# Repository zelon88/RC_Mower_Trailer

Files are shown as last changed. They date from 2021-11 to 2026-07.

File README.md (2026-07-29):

# RC_Mower_Trailer

## WORK IN PROGRESS!!!

A set of SCAD models to 3D Print & Manufacture your own tow-behind lawn mower for R/C trucks.

## Requirements

- Design is about 65% complete. All parts are still subject to change.
- 3D printer with 150mm × 150mm minimum build volume
- Tamiya High-Lift or compatible R/C truck (tow vehicle)
- 540 brushed motors × 2 (standard Silver Can or equivalent)
- 1/10th scale R/C servo × 2 (standard size)
- 1.9" or 2.2" R/C wheels × 4
- Standard R/C battery & ESC (×2, one per motor)
- Steel flat bar — 3.175mm (1/8") thickness for chassis rails & blades
- Standard M2.5, M3, & M5 hardware (screws, nuts, washers, lock washers)
- 10× thrust ball bearings & 2× flanged ball bearings (differential assembly)
- R4 series ball bearings — 1/4" ID × 1/2" OD × 3/16" width (blade carriers)
- Basic hand tools: drill press, files, soldering iron, screwdrivers

## Features At-A-Glance

* A hybrid assembly consisting of 3D printed & manufactured parts.
* Complete with detailed manufacturing & assembly instructions.
* Dual counter-rotating motors for exceptional torque & smoothness.
* Dual counter-rotating cutting blades for smooth, balanced operation.
* Differential gearbox provides rotational shock damping properties while ensuring both motors send power to both blades.
* Uses standard 540 brushed R/C motors, 1/10th scale R/C servos, standard R/C batteries, & 1.9" or 2.2" R/C wheels.
* Highly modular design with many interchangeable parts makes repairs simple & inexpensive.
* Industrial-grade engineering inspired by early 20th century tractors & farm equipment.
* Designed to be manufactured at home using residential-grade tooling & techniques.
* Designed to actually do work. Not a shelf queen. A functional piece of equipment.
* Designed with numerous safety features. See below for more safety information.
* Self-leveling suspension with adjustable ride height.
* Integrated hoppers collect grass clippings and dump them out at the push of a button.

## Features In-Depth

### Counter Rotating Blade Drivetrain

The cutting blades are powered in opposite directions by a pair of "Silver Can" brushed 540 DC electric motors typically found in entry-level R/C vehicles. This motor is inexpensive, reliable, and offers decent performance. The gearbox accepts standard size, standard rotation motors, so most R/C motors will fit.

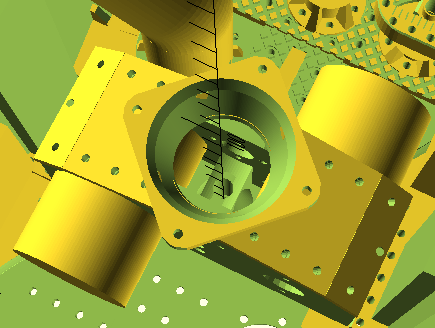
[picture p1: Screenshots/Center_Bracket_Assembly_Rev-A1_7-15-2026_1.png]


The rotation of the motors is joined via a Center Differential. This linked-rotation configuration allows for the equalization of impacts or over-torque events between both blades & both motors. The rotation of the blades being linked together means one blade acts as a flywheel & inertial damper for the other. It also means faster blade speed recovery after an impact, as each blade has torque from both motors. Finally, when our system impacts heavy debris; not all energy is lost like in separate blade systems. In our system, the impact energy is transferred to the opposite blade, actually increasing its velocity. This temporary over-speed condition acts as an inertial "capacitor" that stores energy to be distributed back to the slower blade via the center differential.

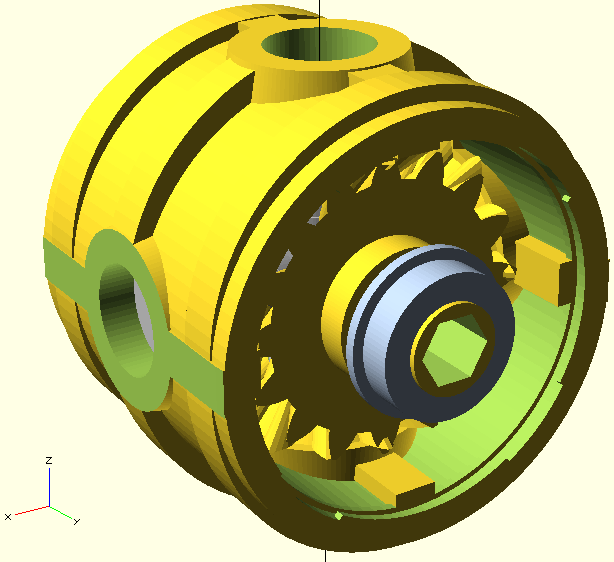
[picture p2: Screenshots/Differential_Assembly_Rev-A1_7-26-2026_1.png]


The differential itself is a modular 3D printable planetary unit measuring 21mm x 21mm x 21mm. Its assembly consists of 2 output gears, 4 planet gears, & a core block. The assembly is supported by 10× thrust ball bearings & 2× flanged ball bearings. Great care has been taken during design to ensure the differential assembly is isolated from shock, over-torque conditions, or unsupported side-loads.

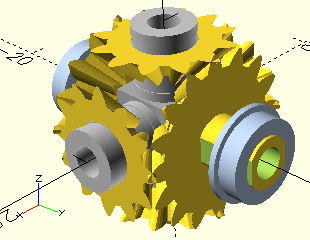
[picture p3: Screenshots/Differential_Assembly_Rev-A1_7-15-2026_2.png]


To compare; in systems with fully separate blade drive systems the energy contained within any blade is only equal to that of the mass of one blade. In our system; each blade contains the full potential energy of both rotating blades. When our system impacts heavy debris our blades keep more of their velocity and stability.

### Inertia Dampened Drivetrain

The drivetrain features dual Inertia Dampers located on either side of the center differential. The inertia dampers are designed to absorb, store, and redistribute kinetic energy from large impacts back into the drivetrain evenly over time. The compact dampers are integrated inside the pulley system which drives the blades. Each damper features quad centering springs which provide 15 degrees of deflection in both clockwise & counter-clockwise directions for 30 degrees of total deflection.

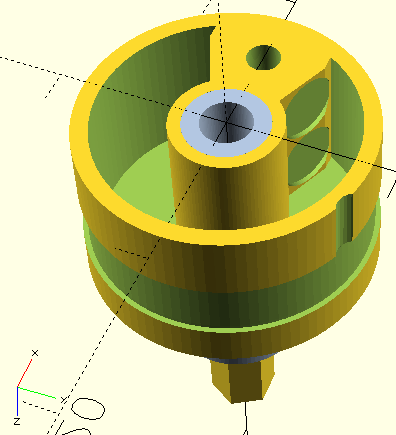
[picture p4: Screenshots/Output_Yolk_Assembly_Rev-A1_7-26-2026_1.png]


Each damper is designed in two main parts; a yolk & a cover. Both the cover & the yolk are open-ended interlocking drums. The drums can rotate independantly clockwise or counter-clockwise from one another via 3x internal ball bearings and a massive 18mm x 3.6mm tapered roller bearing integrated into the body of the two drums. Although the drums can rotate up to 15 degrees off-center from one another, they are pre-loaded to stay centered via 4x internal springs. The internal springs act to keep the drums centered, but will allow separation up to 15 degrees clockwise or counter-clockwise to absorb sudden drastic changes in load.

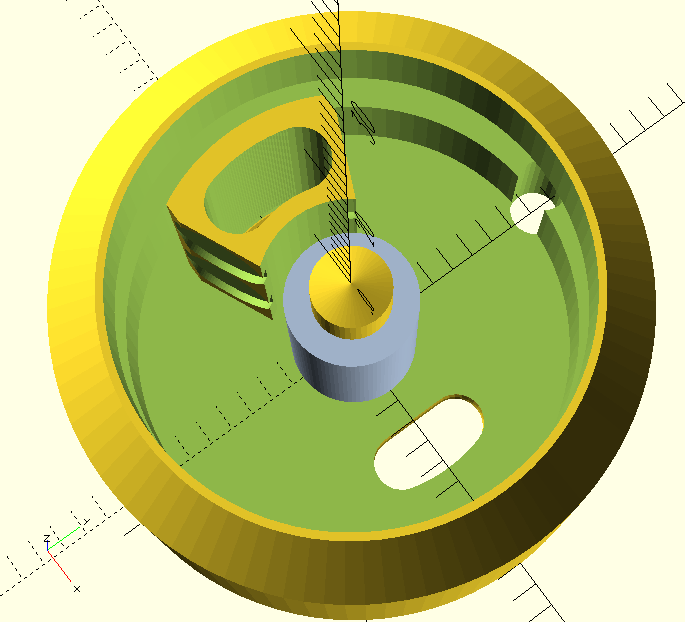
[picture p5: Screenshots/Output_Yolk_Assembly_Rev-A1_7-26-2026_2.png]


It is important to note that the motors are not protected by the inertial damper. The dampers exist to protect the differential gears from exposure to overwhelming force by spreading that force over a longer duration of time. The motors rotate the cover of the inertial damper, and the center differential is attached to the center yolk. When a blade decelerates due to impacted debris; the motor is also slowed instantly. Because the motor is located outside the protection of the damper, it's acceleration torque actually helps the inertial damper recover sooner. Additionally, the energy stored by the spring in the damper is redirected back into the motor as additional torque during re-acceleration. 

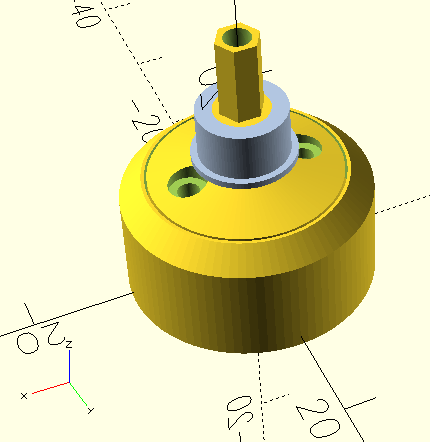
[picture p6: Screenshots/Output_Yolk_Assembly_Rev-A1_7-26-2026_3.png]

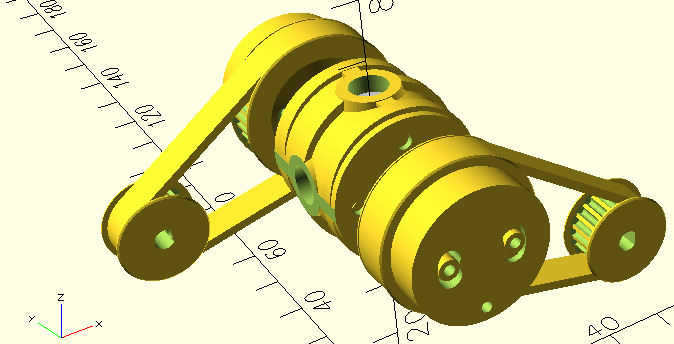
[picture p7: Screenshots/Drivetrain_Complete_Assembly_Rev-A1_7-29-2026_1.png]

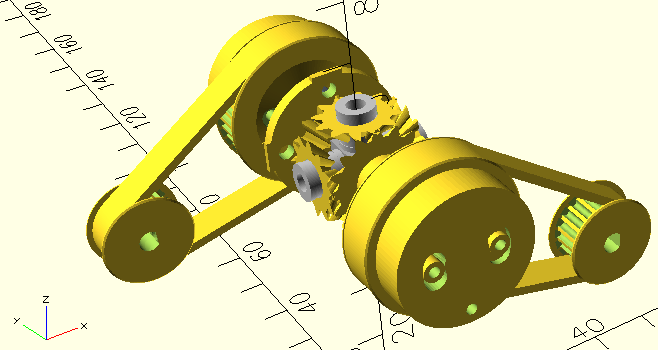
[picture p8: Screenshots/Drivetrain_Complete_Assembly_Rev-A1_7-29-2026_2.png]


Everything about our blade drive system is designed to control, absorb, store, & distribute kinetic energy in the most stable & efficient way possible.

### Steel Reinforced Chassis

Every design element has been carefully selected with heavy consideration towards containing debris, managing vibration, surviving impact, & providing durability.

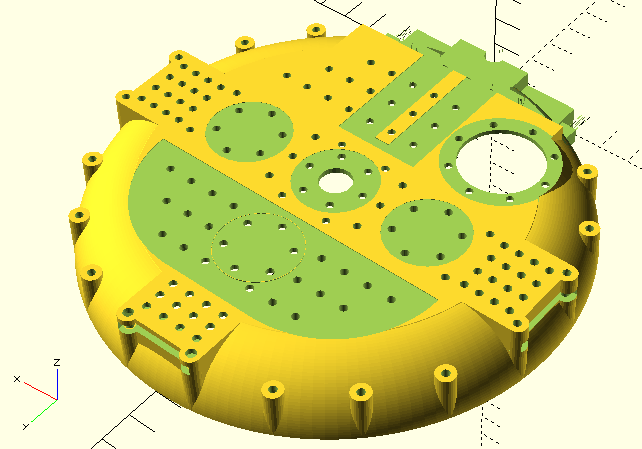
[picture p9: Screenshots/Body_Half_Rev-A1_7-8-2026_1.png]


The mower chassis is comprised of a steel frame with a thickness between 3.175mm and 6.35mm. Wrapped around this steel frame is an impact resistant plastic body with a thickness between 4mm and 14mm. The average material thickness around the rotating blades is 10mm with additional plastic gussets and steel screws built into the body every 19 degrees around the circumference of the blade.

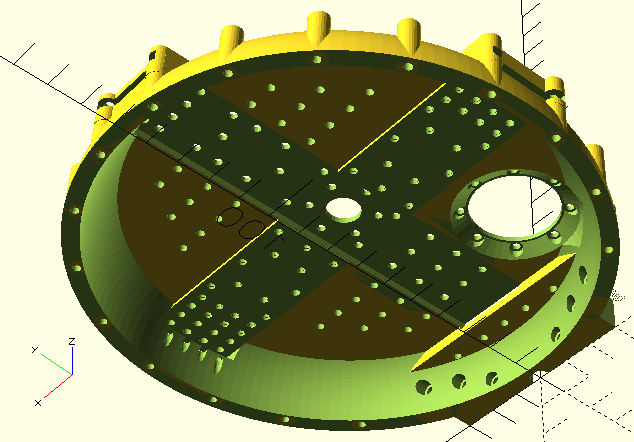
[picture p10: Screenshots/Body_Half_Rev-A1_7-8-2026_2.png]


### Captured Blade Carrier Design

The cutting blades are made from 3.175mm thick steel flat bar. The blades rotate in opposite directions to minimize vibration and prevent build-up of gyroscopic forces that could destabilize the mower. The blades are installed via a very long grade 8 bolt which traverses a through hole in the center of the blade. This bolt is then installed into the chassis from the bottom-up through three stages of ball bearings.

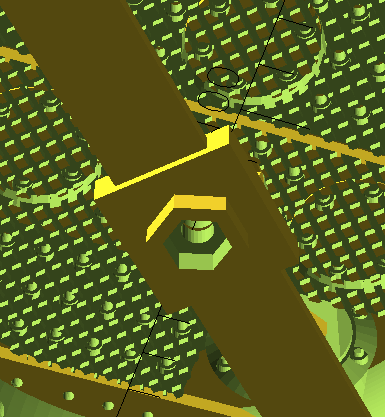
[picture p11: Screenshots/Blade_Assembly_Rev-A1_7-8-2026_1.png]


Due to the length of the bolt being greater than the clearance from the blade to the ground; it is impossible for a spinning blade to "fall out" or "swing out" from underneath a running mower.

### Redundant Rollover Protection

The mower features blueprints & instructions for building dual Rollover Protection Switches which disable the mower automatically in the event that it tips over. The adjustable switches will prevent the blade motors and blades from spinning while the mower is inverted. The switches self-reset once the mower has been placed upright again.

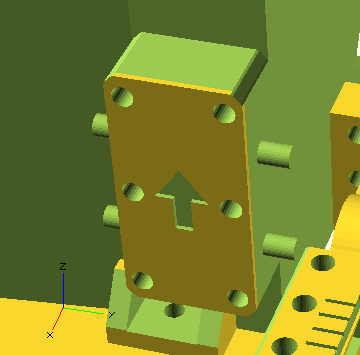
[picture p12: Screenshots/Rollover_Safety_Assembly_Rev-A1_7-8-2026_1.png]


The switches are incredibly small, at only 30mm × 15mm × 8.5mm each. They feature a modular design with optional input/output terminals on left & right sides.

When using only one input & one output terminal, observed current is similar to a 14 AWG wire. When using both sets of terminals, observed current is similar to a 12 AWG wire. Two switches are included in this mower design, wired in series to provide double fault tolerant rollover protection.

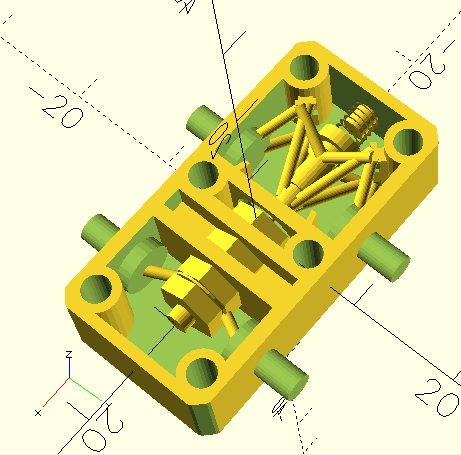
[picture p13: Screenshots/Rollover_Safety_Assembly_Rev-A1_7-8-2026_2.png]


### Multi-Mode Self-Leveling Suspension

The mower features independent self-leveling suspension on all 4 wheels & side attachments. The suspension features prominent adjustment screws that enable the operator to quickly & easily adjust cutting height & side attachment height. The geometry of the suspension is designed to be identical between front, rear, and side suspension arms to simplify assembly & field repair.

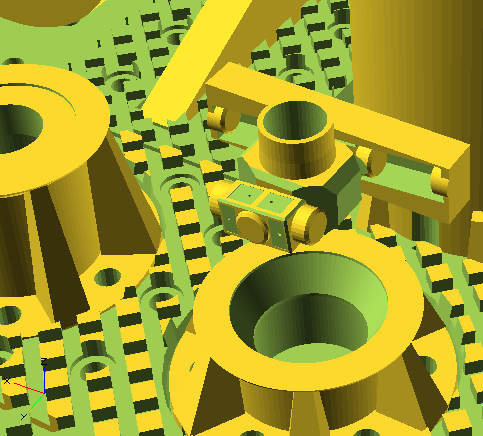
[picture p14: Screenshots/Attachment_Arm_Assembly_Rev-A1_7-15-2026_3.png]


The geometry for the suspension is contained in modular "Ramp Inserts" which feature a reversible design. When these inserts are installed into the suspension arms in the "reversed" position, the damping behaviour of the suspension is altered significantly.

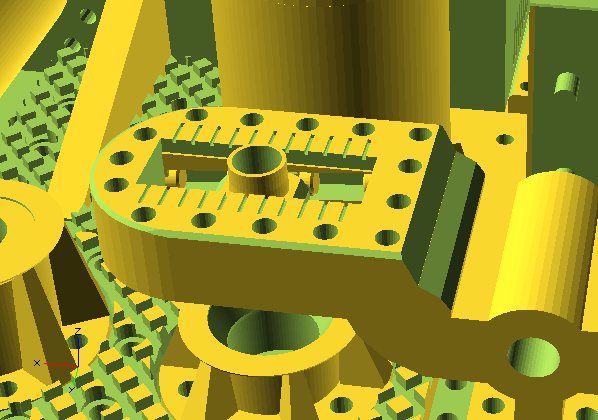
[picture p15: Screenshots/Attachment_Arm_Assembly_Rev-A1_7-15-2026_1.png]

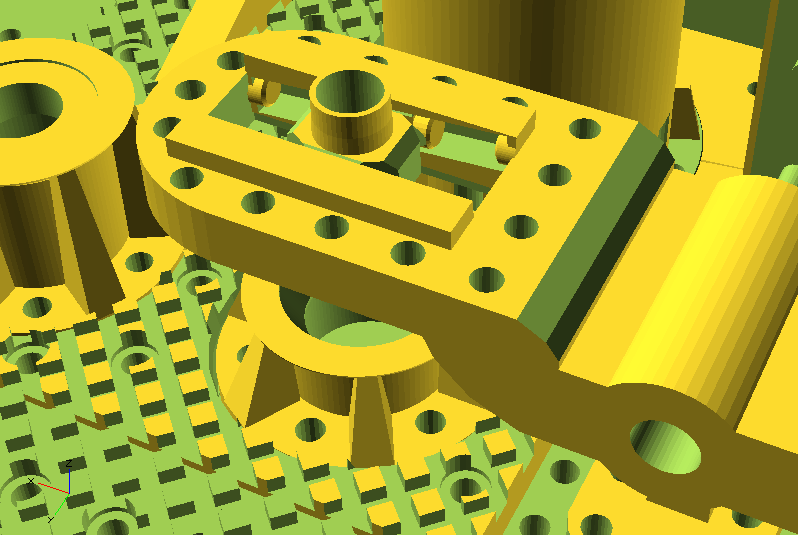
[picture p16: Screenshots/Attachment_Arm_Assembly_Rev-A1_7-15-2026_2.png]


In the "**Default**" ramp insert position, the mower will "**Follow The Ground**." In this configuration the wheel will primarily travel and absorb bumps in the downward direction only. The adjustment screws that set height will set the "absolute floor" for ride-height that the suspension will not allow height to go beneath. When one wheel falls into a rut, that wheel will be allowed to gently follow the rut, and recover to its original position naturally. The default configuration allows each suspension arm to independently absorb low spots in terrain without the entire body "tilting" or the blades "digging" into the ground. The mower will seem to be "latched" to the ground. This configuration is best suited for relatively smooth lawns.

In the "**Reversed**" ramp insert position, the mower will "**Stay Level**." In this configuration the wheel will travel and absorb bumps in both the upward and downward directions. The adjustment screws that set height will set the "absolute ceiling" for ride-height that the suspension will not allow height to go above. Due to the spring rate being very low, the result is the suspension will sag somewhere in the middle of its ride height. This will allow the wheel to travel and absorb bumps in both the upward & downward directions. The adjustment screw effectively sets a middle resting position for the suspension. The reversed configuration allows each suspension arm to independently absorb high spots and low spots in extremely uneven terrain, but with greater risk for the body "tilting" or the blades "digging" into the ground. The mower will seem to be "floating" over the ground. This configuration is best suited for tall grass, uneven terrain, or heavy brush.

The same suspension logic applies to the side attachment suspension assembly. The parts and geometry are all identical, but the "Reversed" position is used as the default ramp insert configuration.

Damping is achieved via friction dampers integrated into the Attachment Adjustment Arm Crossheads. The crossheads bear the load of the suspension from the suspension arm to the adjustment screw. They feature grease pockets, grease galleries, calculated surface area & carefully crafted geometry to optimize load handling & damping characteristics in an especially reliable & cost effective way.

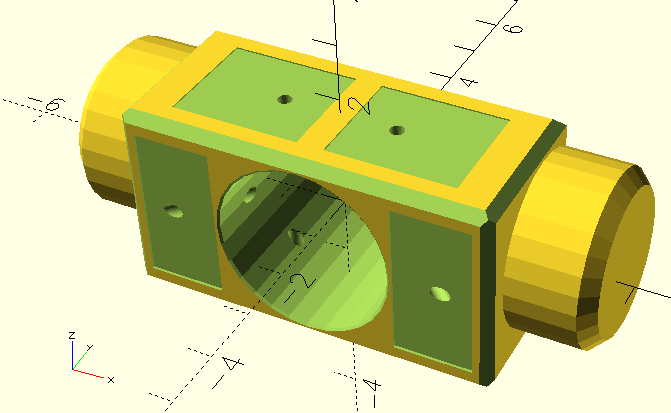
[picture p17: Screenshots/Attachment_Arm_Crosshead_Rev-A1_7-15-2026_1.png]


## More Screenshots

### [View All Screenshots](https://github.com/zelon88/RC_Mower_Trailer/tree/main/Screenshots)

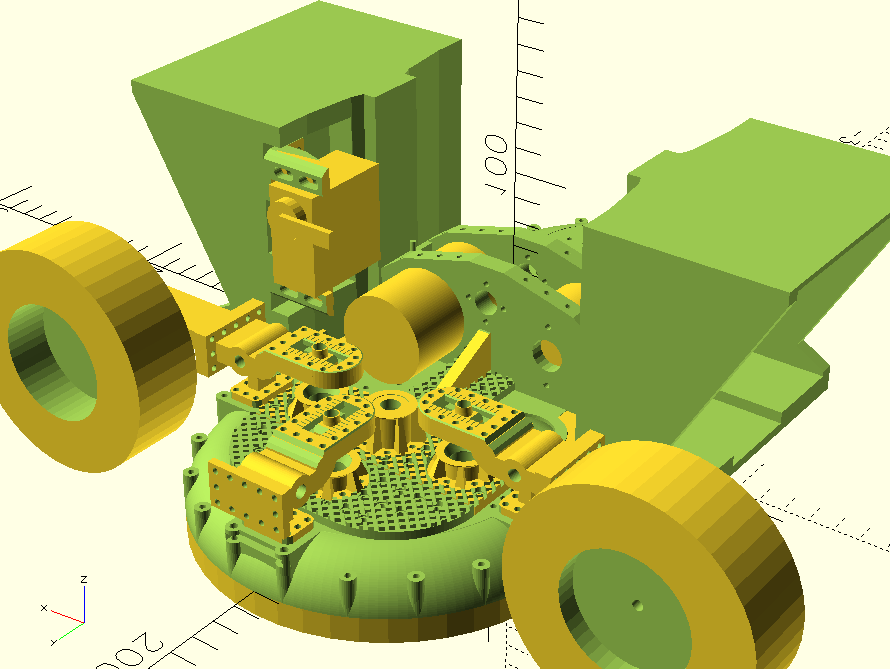
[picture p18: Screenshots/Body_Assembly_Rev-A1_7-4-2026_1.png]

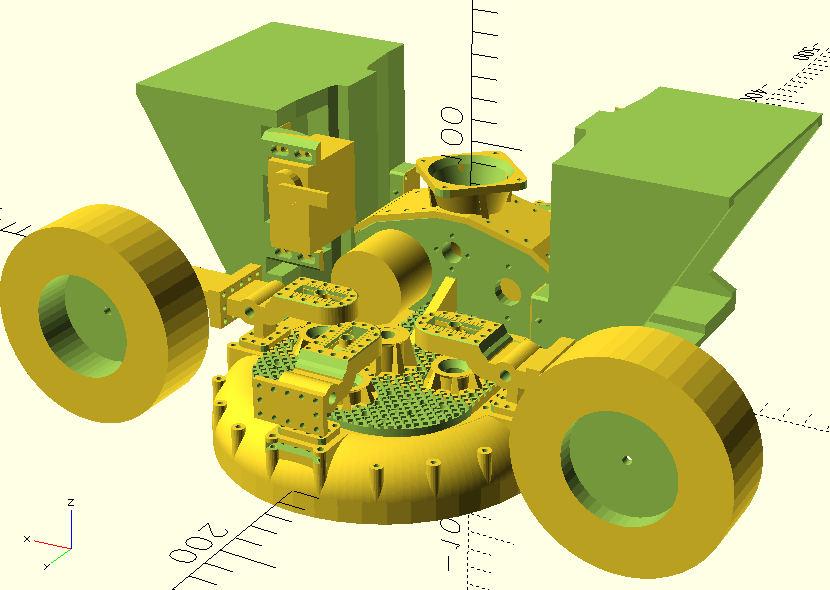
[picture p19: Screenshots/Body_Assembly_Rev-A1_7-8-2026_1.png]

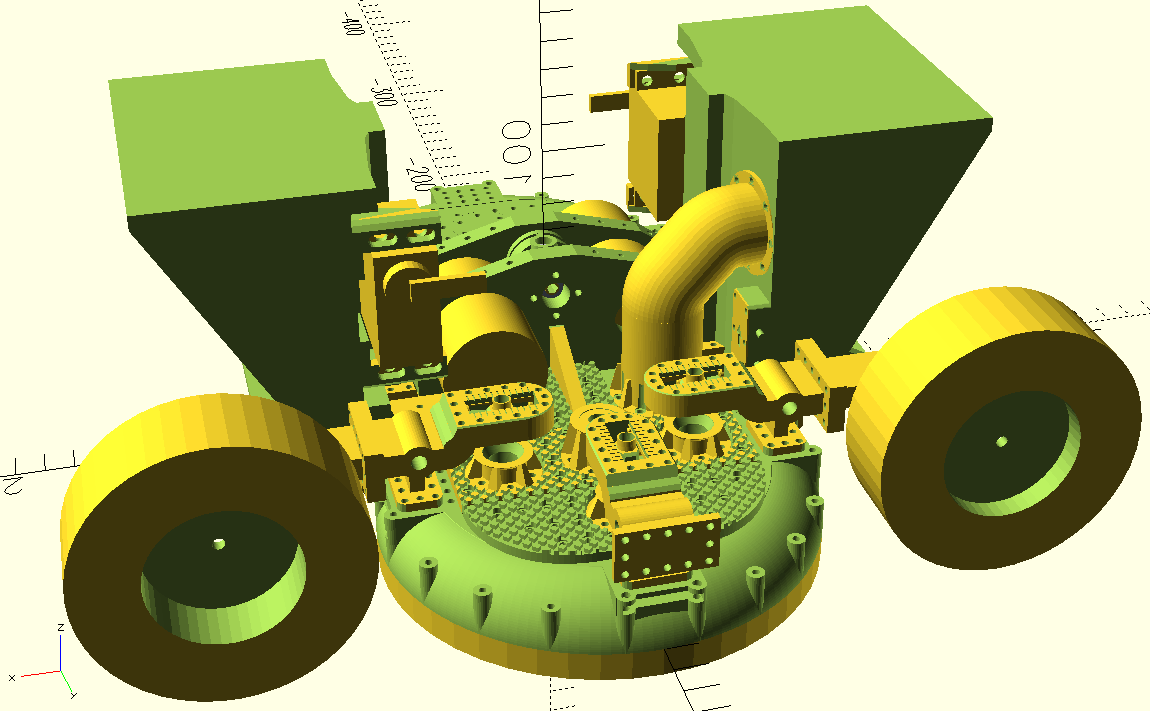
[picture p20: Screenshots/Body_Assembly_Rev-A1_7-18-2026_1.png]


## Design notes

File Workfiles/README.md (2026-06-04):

# RC_Mower_Trailer
 A set of SCAD models for a tow-behind lawn mower attachment for R/C trucks.

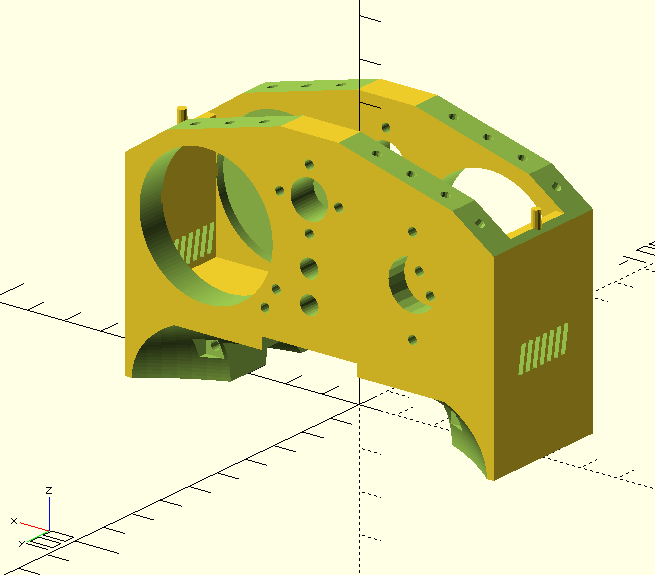
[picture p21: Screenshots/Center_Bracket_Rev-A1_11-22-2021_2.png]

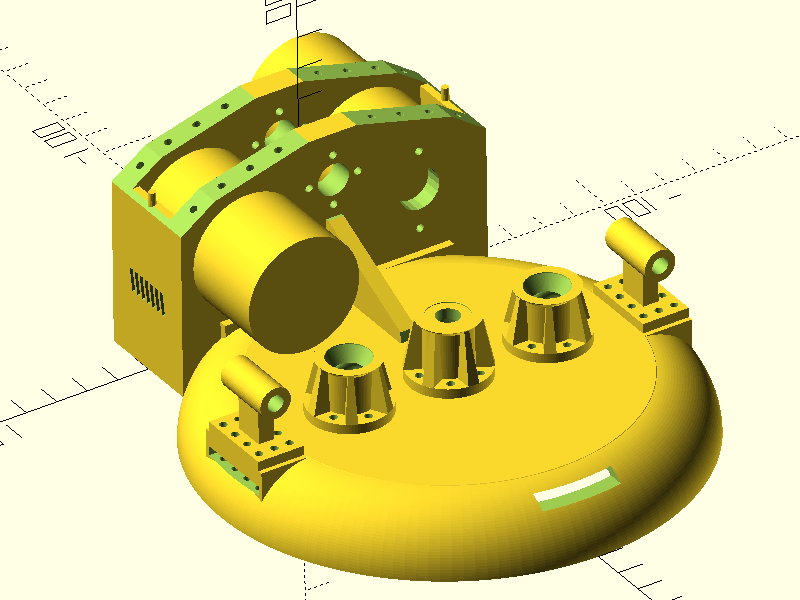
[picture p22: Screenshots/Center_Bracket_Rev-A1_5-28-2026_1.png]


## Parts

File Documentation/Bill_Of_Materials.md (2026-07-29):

# R/C Mower Trailer — Bill of Materials

**Status: design phase.** Counts here are taken from the SCAD sources, not from a build.
Anything marked ⚠ has not been verified against a physical assembly and anything marked
❓ could not be counted from the files available. This gets rebuilt properly during the
manufacturing engineering pass, when print orientation and hardware lengths are settled.

Quantities are **per mower** unless stated otherwise.

---

## 1. Drivetrain

Fully counted from source. This is the part of the machine that is dimensionally closed —
every item below is driven by a specific feature in a specific file.

### 1.1 Center Differential — printed

| Qty | Part | File |
|---|---|---|
| 1 | Differential Housing | `Differential_Housing.scad` |
| 1 | Differential Housing Cap | `Differential_Housing_Cap.scad` |
| 1 | Core Block | `Differential_Gears.scad` → `cross_block_core()` |
| 2 | Output Gear (16T bevel, with shaft) | `Differential_Gears.scad` → `side_gear_with_shaft()` |
| 4 | Planet Gear (12T bevel) | `Differential_Gears.scad` → `planet_bevel_gear()` |

### 1.2 Center Differential — hardware

| Qty | Item | Notes |
|---|---|---|
| 10 | F3-6-2.8M thrust bearing | 8 on the planets (2 each), 2 inboard on the output gears |
| 2 | 5×8×2.5mm **flanged** ball bearing | One per output shaft, flange toward the gear |
| 2 | M2.5 wave compression washer | One per output shaft |
| 4 | M2.5 conical compression washer | One per planet, small dia toward the gear |
| 4 | M2.5 planet gear screw | Threads into the core block; use thread locker |
| 1 | M2.5 output gear through bolt ⚠ | Length not yet fixed — spans both output gears |
| — | M2.5 flat washers | **Shimmed at assembly.** Equal count each side of each planet, added until gear slack is gone. Buy generously. |
| 4 | M2.5 screw, housing to cap | Holes at X=±8 and Z=45/61 in both parts |

### 1.3 Inertia Dampers — printed (**×2 dampers**)

| Qty (each) | Qty (total) | Part | File |
|---|---|---|---|
| 1 | 2 | Output Yolk | `Differential_Output_Yolk.scad` |
| 1 | 2 | Output Yolk Cover | `Differential_Output_Yolk_Cover.scad` |
| 30 | **60** | Conical Roller Bearing | `Differential_Output_Yolk_Roller_Bearing.scad` |

The roller count is set by `roller_qty` in the yolk's assembly block. 30 gives 0.232mm of
gap between rollers on the 9.16685mm pitch radius. Print spares — they are 1.7mm across
and will be lost.

### 1.4 Inertia Dampers — hardware (**×2 dampers**)

| Qty (each) | Qty (total) | Item | Notes |
|---|---|---|---|
| 3 | 6 | 3×5×2.5mm ball bearing | Stacked at Z=0, 2.5, 5 on the yolk pin |
| 1 | 2 | 5×8×2.5mm **flanged** ball bearing | At Z=14.5 |
| 1 | 2 | 5×8×2.5mm ball bearing | At Z=14.5 |
| 2 | 4 | M1.6 screw ⚠ | Through the standoff bosses at X=±5.25. Length not yet fixed — the boss is 9.5625mm and the head recesses into the yolk. |
| 2 | 4 | M1.6 lock nut | Lands on the boss end, not on the cover cap |
| 4 | 8 | Compression spring ⚠ | "Clicky pen" springs, 2 per trapezoid face. Free length and rate not yet specified. |

### 1.5 Belt Drive

| Qty | Item | Notes |
|---|---|---|
| 2 | Motor Pulley, 19T | Printed — `Differential_Motor_Pulley.scad` |
| 2 | M2.5 set screw ⚠ | Forms its own thread in the tapered hole. ~4mm long; not yet fixed. |
| 2 | GT2 belt, **120mm** (60T), 6mm wide, closed loop | Fibreglass corded |
| — | Driven pulley, 38T | **Not a separate part** — cut into the Output Yolk Cover |

Ratio is exactly 2.000:1. Centre distance is fixed by the Center Bracket at 30.8707mm;
a 120mm belt wants 30.9083mm, so it runs 0.0376mm slack with no adjuster anywhere. Do not
substitute a 122mm belt — that wants 31.4786mm and will be visibly loose.

### 1.6 Motors

| Qty | Item | Notes |
|---|---|---|
| 2 | 540 brushed motor, "Silver Can" or equivalent | 3.175mm armature shaft **with a flat**. The pulley bore is a D and relies on it. |
| 2 | Brushed ESC ⚠ | Rating not yet specified |

---

## 2. Chassis and Body — partial

Counted where files were available. **Fastener counts here are not yet trustworthy**: many
holes are shared between mating parts, so a hole is not a screw, and several referenced
`Workfiles/` hole-pattern modules were not available to expand.

| Qty | Part | File | Confidence |
|---|---|---|---|
| 2 | Body Half | `Body_Half.scad` | counted |
| 1 | Center Bracket | `Center_Bracket.scad` | counted |
| 2 | Center Bracket Support | `Center_Bracket_Support.scad` | counted |
| 1 | Clippings Exhaust Header | `Clippings_Exhaust_Header.scad` | counted |
| ❓ | Body Skirt | `Body_Skirt.scad` | not available |
| ❓ | Body Stiffener, Inner / Outer / Center | `Body_Stiffener_*.scad` | not available |
| ❓ | Center Bracket Skid Plate | referenced in Body Half Assembly | not available |
| ❓ | Hopper Base, Hopper Bracket | referenced in Body Half Assembly | not available |
| ❓ | Attachment Hinge Boss | referenced in Body Half Assembly | not available |

### Steel stock

| Item | Notes |
|---|---|
| Flat bar, 3.175mm (1/8") | Chassis rails, X and Y slots in the torus base. Slot is 25.6mm wide × 3.175mm. |
| Flat bar, 3.175mm (1/8") | Cutting blades ❓ — length and count not counted |

---

## 3. Not yet counted

These need their files before anything honest can be said about them:

- **Blade carriers** — README calls for R4 bearings (1/4" ID × 1/2" OD × 3/16"), quantity unknown
- **Blade retention bolts** — grade 8, "longer than ground clearance"; length not fixed
- **Suspension** — Attachment Adjustment Arms, ramp inserts, crossheads, springs, adjustment screws
- **Rollover Safety Switches** — 2 off, plus their gravity pins, castle nuts and terminals
- **Wheels** — 4× 1.9" or 2.2" R/C
- **Servos** — 2× standard 1/10 scale
- **Batteries** — 2× standard R/C
- **Hoppers** and their dump mechanism
- **General fasteners** — M2.5 / M3 / M5 screws, nuts, washers, lock washers across the whole machine

---

## 4. Open questions for the manufacturing pass

1. **Screw lengths are unspecified throughout.** Every ⚠ above is a length that needs
   measuring off an assembled stack rather than guessing from the model.
2. **The damper spring rate is undefined.** Preload sets the ±15° deflection behaviour,
   and the spring is currently described only as "clicky pen spring".
3. **Roller count is a design choice, not a constraint.** 30 was chosen for spacing; more
   would spread the preload further, up to about 36 before they touch.
4. **The GT2 tooth profile is unverified.** It is the one set of numbers in the drivetrain
   taken from an external source rather than derived. Fit a real belt to a printed pulley
   before committing to a print run.
5. **Damper bearings are absent from the README requirements list.** It currently
   attributes 10 thrust and 2 flanged bearings to the differential only, which is correct
   as far as it goes, but the 6 + 2 + 2 in section 1.4 are additional and unlisted.

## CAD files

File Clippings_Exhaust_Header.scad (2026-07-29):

// ----------------------------------------------------------------------------------------------------
// PROJECT INFORMATION

// NAME:  R/C Mower Trailer
// REVISION:  A1
// START DATE:  8/20/2021
// CURRENT VERSION DATE:  9/8/2021
// LICENSE:  GPLv3
// AUTHOR:  Justin Grimes (@zelon88)
// DESCRIPTION:  A tow-behind lawn mowing attachment for retrofit onto low-speed R/C vehicles.
// ----------------------------------------------------------------------------------------------------

// ----------------------------------------------------------------------------------------------------
// PART INFORMATION

// NAME:  Clippings Exhaust Header
// REVISION:  A1
// START DATE:  7/4/2026
// CURRENT VERSION DATE:  7/16/2026
// AUTHOR:  Justin Grimes (@zelon88) & Copilot - Claude Sonnet 4.6.
// DESCRIPTION:
//    A clippings evacuation header routing grass clippings from the cutting deck to the hopper.
//    Features a bottom flange mating to Body_Half, an 8x rib reinforced straight tube, a first
//    45deg elbow, an extension pipe with an oval intermediate support ring (10x screw holes for
//    body attachment), a second 45deg elbow bringing the pipe to horizontal, a short horizontal
//    pipe section, and a terminal circular flange mating flush with the X face of the hopper.
//    The terminal flange faces world +X. index_angle introduces a small rotation that can be
//    zeroed to achieve exact X-perpendicular alignment if needed.
// FILE NAME: Clippings_Exhaust_Header.scad
// ----------------------------------------------------------------------------------------------------

// ----------------------------------------------------------------------------------------------------
// PRINTER CONFIGURATION
// [Printing instructions to be added]
// ----------------------------------------------------------------------------------------------------

// ----------------------------------------------------------------------------------------------------
// MANUFACTURING INSTRUCTIONS

// 1. Deburr all edges to break sharp edges.
// 2. Align bottom flange screw holes with Clippings_Flange_Screw_Holes() on Body_Half.
// 3. Fasten bottom flange with M2.5 screws.
// 4. Fasten oval intermediate ring to nearby body structure for pipe support.
// 5. Align terminal circular flange with matching hole in hopper X face and bolt together.
// ----------------------------------------------------------------------------------------------------

// ----------------------------------------------------------------------------------------------------
// MODULES

include <Workfiles/Clippings_Flange_Screw_Holes.scad>
// A module for cutting the 8x screw holes in the terminal X-facing circular flange.
include <Workfiles/Clippings_X_Flange_Screw_Holes.scad>
// ----------------------------------------------------------------------------------------------------

// ----------------------------------------------------------------------------------------------------
// GEOMETRY

module Clippings_Flange_Exhaust_Header() {
  // Primary dimensions.
  flange_r    = 18;   // Bottom flange outer radius.
  flange_t    = 2.5;  // Bottom flange thickness.
  flange_id   = 13;   // Bottom flange inner bore radius.
  tube_id     = 13;   // Tube inner radius (all sections).
  tube_od     = 14;   // Tube outer radius — 1mm wall (all sections).
  tube_h      = 35;   // Straight tube height above bottom flange.
  bend_r      = 14;   // Centerline bend radius — same for all elbows.
  bend_angle  = 45;   // First and second elbow bend angle from vertical (degrees).
  index_angle = 6.5;  // Z rotation orienting the first elbow toward the hopper.
                      // Set to 0 for exact world +X terminal flange alignment.
  ext_h       = 15;   // Extension pipe length between first and second elbows.
  pipe_x_h    = 7;    // Short pipe length in world +X direction after second elbow.

  // Rib dimensions.
  rib_base_d = flange_r - tube_od;
  rib_top_d  = 1.5;
  rib_base_w = 2.5;
  rib_top_w  = 1.2;
  rib_h      = 10;

  // Oval intermediate ring dimensions.
  oval_margin = 3;
  oval_t      = 2.5;
  oval_a_out  = tube_od / cos(bend_angle) + oval_margin;
  oval_b_out  = tube_od + oval_margin;
  oval_a_in   = tube_id / cos(bend_angle);
  oval_b_in   = tube_id;

  // Terminal circular flange dimensions (mates with hopper X face).
  x_flange_r  = 18;    // Terminal flange outer radius.
  x_flange_t  = 3;   // Flange plate thickness.

  difference() {
    union() {
      // Bottom flange plate.
      cylinder($fn=256, r=flange_r, h=flange_t, center=false);
      // Straight tube.
      translate([0, 0, flange_t]) cylinder($fn=256, r=tube_od, h=tube_h, center=false);
      // Tapered ribs (8x, between screw holes).
      for (i = [0:7]) {
        rotate([0, 0, i * 45 + 22.5])
        hull() {
          translate([tube_od + rib_base_d/2, 0, flange_t])
            cube([rib_base_d, rib_base_w, 0.01], center=true);
          translate([tube_od + rib_top_d/2, 0, flange_t + rib_h])
            cube([rib_top_d, rib_top_w, 0.01], center=true); } }
      // First 45deg elbow (vertical to 45deg tilt).
      rotate([0, 0, index_angle])
      translate([0, 0, flange_t + tube_h])
      translate([bend_r, 0, 0])
      rotate([0, 0, 180])
      rotate([90, 0, 0])
      rotate_extrude(angle=bend_angle, $fn=256)
        translate([bend_r, 0]) circle(r=tube_od, $fn=128);
      // Extension pipe.
      rotate([0, 0, index_angle])
      translate([0, 0, flange_t + tube_h])
      translate([bend_r*(1-cos(bend_angle)), 0, bend_r*sin(bend_angle)])
      rotate([0, 45, 0])
        cylinder($fn=128, r=tube_od, h=ext_h + 1, center=false);
      // Second 45deg elbow (pipe direction to horizontal = world +X approximately).
      rotate([0, 0, index_angle])
      translate([0, 0, flange_t + tube_h])
      translate([bend_r*(1-cos(bend_angle)), 0, bend_r*sin(bend_angle)])
      rotate([0, 45, 0])
      translate([0, 0, ext_h])
      translate([bend_r, 0, 0])
      rotate([0, 0, 180])
      rotate([90, 0, 0])
      rotate_extrude(angle=bend_angle, $fn=256)
        translate([bend_r, 0]) circle(r=tube_od, $fn=128);
      // Short pipe in world +X direction.
      // In pipe local frame, rotate([0,45,0]) aligns the cylinder axis with
      // local (sin45,0,cos45) = world +X. Terminal face is perpendicular to world +X.
      rotate([0, 0, index_angle])
      translate([0, 0, flange_t + tube_h])
      translate([bend_r*(1-cos(bend_angle)), 0, bend_r*sin(bend_angle)])
      rotate([0, 45, 0])
      translate([bend_r*(1-cos(bend_angle)), 0, ext_h + bend_r*sin(bend_angle)])
      rotate([0, 45, 0])
        cylinder($fn=128, r=tube_od, h=pipe_x_h, center=false);
      // Terminal circular flange — face perpendicular to world +X, mates with hopper X face.
      rotate([0, 0, index_angle])
      translate([0, 0, flange_t + tube_h])
      translate([bend_r*(1-cos(bend_angle)), 0, bend_r*sin(bend_angle)])
      rotate([0, 45, 0])
      translate([bend_r*(1-cos(bend_angle)), 0, ext_h + bend_r*sin(bend_angle)])
      rotate([0, 45, 0])
      translate([0, 0, pipe_x_h])
        cylinder($fn=256, r=x_flange_r, h=x_flange_t, center=false); }
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

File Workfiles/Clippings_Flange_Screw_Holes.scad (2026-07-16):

// ----------------------------------------------------------------------------------------------------
// PROJECT INFORMATION

// NAME:  R/C Mower Trailer
// REVISION:  A1
// START DATE:  8/20/2021
// CURRENT VERSION DATE:  9/8/2021
// LICENSE:  GPLv3
// AUTHOR:  Justin Grimes (@zelon88)
// DESCRIPTION:  A tow-behind lawn mowing attachment for retrofit onto low-speed R/C vehicles.
// ----------------------------------------------------------------------------------------------------

// ----------------------------------------------------------------------------------------------------
// PART INFORMATION

// NAME:  Clippings Flange Screw Holes
// REVISION:  A1
// START DATE:  7/6/2026
// CURRENT VERSION DATE:  7/6/2026
// AUTHOR:  Justin Grimes (@zelon88)
// DESCRIPTION:
//    A reusable module that cuts the 8-hole screw pattern for the clippings flange,
//    including a deep screw recess on the bottom (-Z) face.
// FILE NAME: Clippings_Flange_Screw_Holes.scad
// ----------------------------------------------------------------------------------------------------

// ----------------------------------------------------------------------------------------------------
// PRINTER CONFIGURATION
// [Printing instructions to be added]
// ----------------------------------------------------------------------------------------------------

// ----------------------------------------------------------------------------------------------------
// MANUFACTURING INSTRUCTIONS
// [Manufacturing instructions to be added]
// ----------------------------------------------------------------------------------------------------

// ----------------------------------------------------------------------------------------------------
// GEOMETRY

module Clippings_Flange_Screw_Holes() {
  // Clippings flange screw holes with deep screw recess on bottom (-Z) face.
  for (i = [0:7]) {
    translate([15.25 * cos(i * 45), 15.25 * sin(i * 45), 0]) {
      // Through hole.
      cylinder($fn=28, r=1.22, h=15, center=false);
      // Deep screw recess on bottom (-Z) face.
      translate([0, 0, -5]) cylinder($fn=28, r=2, h=10, center=false); } } }

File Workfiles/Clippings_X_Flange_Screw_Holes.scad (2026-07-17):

// ----------------------------------------------------------------------------------------------------
// PROJECT INFORMATION

// NAME:  R/C Mower Trailer
// REVISION:  A1
// START DATE:  8/20/2021
// CURRENT VERSION DATE:  9/8/2021
// LICENSE:  GPLv3
// AUTHOR:  Justin Grimes (@zelon88)
// DESCRIPTION:  A tow-behind lawn mowing attachment for retrofit onto low-speed R/C vehicles.
// ----------------------------------------------------------------------------------------------------

// ----------------------------------------------------------------------------------------------------
// PART INFORMATION

// NAME:  Clippings X Flange Screw Holes
// REVISION:  A1
// START DATE:  7/16/2026
// CURRENT VERSION DATE:  7/16/2026
// AUTHOR:  Justin Grimes (@zelon88) & Copilot - Claude Sonnet 4.6.
// DESCRIPTION:
//    Two reusable modules for the terminal X-facing flange of Clippings_Exhaust_Header:
//
//    Clippings_X_Flange_Screw_Holes() — cuts the 8-hole screw pattern into the flange itself.
//    Call inside a difference() using the same transform chain as the terminal flange.
//    Holes at r=16 on the midpoint circle. Recesses on -Z (pipe-facing) side for tool access.
//
//    Clippings_X_Flange_Mating_Cut() — cuts the full flange mating surface into the hopper wall.
//    Contains the complete transform chain from the header module origin to the flange face.
//    Drop into the hopper difference() block with the same translate/rotate as the header:
//      translate([-32, 40, 19.75]) rotate([0, 0, 180]) Clippings_X_Flange_Mating_Cut();
//    Values are hardcoded from Clippings_Exhaust_Header — update both files if dimensions change.
//    Cuts: flange pocket (r=22, d=2.5mm), through bore (r=13), 8x screw holes (r=1.22).
// FILE NAME: Clippings_X_Flange_Screw_Holes.scad
// ----------------------------------------------------------------------------------------------------

// ----------------------------------------------------------------------------------------------------
// GEOMETRY

module Clippings_X_Flange_Screw_Holes() {
  // 8x screw holes with deep recess on -Z (pipe-facing) face.
  // Must match x_flange_r and tube_id in Clippings_Exhaust_Header.scad.
  for (i = [0:7]) {
    translate([16 * cos(i * 45), 16 * sin(i * 45), 0]) {
      // Through hole.
      cylinder($fn=28, r=1.22, h=10, center=false);
      // Deep screw recess on -Z face for installation access from pipe side.
      translate([0, 0, -5]) cylinder($fn=28, r=2, h=5, center=false); } } }

module Clippings_X_Flange_Mating_Cut() {
  // Cuts the full flange mating surface into the hopper wall.
  // Replicates the exact transform chain from Clippings_Exhaust_Header to the flange face.
  // Hardcoded from: index_angle=3.75, bend_r=14, bend_angle=45, flange_t=2.5,
  //                 tube_h=40, ext_h=20, pipe_x_h=5.
  // Derived: bend_r*(1-cos45)=4.1, bend_r*sin45=9.9, flange_t+tube_h=42.5.
  // Update these values if any primary dimensions change in the header module.
  rotate([0, 0, 7.5])
  translate([0, 0, 42.5])
  translate([4.1, 0, 9.9])
  rotate([0, 45, 0])
  translate([4.1, 0, 29.9])
  rotate([0, 45, 0])
  translate([0, 0, 5]) {
    // Flange pocket — seats the flange plate flush with the hopper wall exterior.
    cylinder($fn=96, r=18, h=2.5, center=false);
    // Through bore — clears the pipe through the hopper wall.
    cylinder($fn=96, r=13, h=50, center=false);
    // 8x screw holes through hopper wall — matching the flange hole pattern.
    for (i = [0:7]) {
      translate([16 * cos(i * 45), 16 * sin(i * 45), 0])
        cylinder($fn=28, r=1.22, h=20, center=false); } } }
// ----------------------------------------------------------------------------------------------------

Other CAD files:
Attachment_Adjustment_Arm.scad
1_Inch_Flange_Plug.scad
Attachment_Adjustment_Arm_Assembly.scad
Attachment_Adjustment_Arm_Cover.scad
Attachment_Adjustment_Arm_Crosshead.scad
Attachment_Adjustment_Arm_Insert.scad
Attachment_Adjustment_Arm_Ramp_Insert.scad
Attachment_Hinge_Boss.scad
Ball_Joint_Ball.scad
Ball_Joint_Receiver.scad
Bearing_Carrier_Dual.scad
Bearing_Carrier_Single.scad
Blade.scad
Blade_Holder.scad
Body_Assembly.scad
Body_Half.scad
Body_Half_Assembly.scad
Body_Skirt.scad
Body_Stiffener_Center.scad
Body_Stiffener_Inner.scad
Body_Stiffener_Inner_Lower.scad
Body_Stiffener_Outer.scad
Center_Bracket.scad
Center_Bracket_Skid_Plate.scad
Center_Bracket_Support.scad
Differential_Drive_Belt.scad
Differential_Gears.scad
Differential_Housing.scad
Differential_Housing_Cap.scad
Differential_Motor_Pulley.scad
Differential_Output_Yolk.scad
Differential_Output_Yolk_Assembly.scad
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

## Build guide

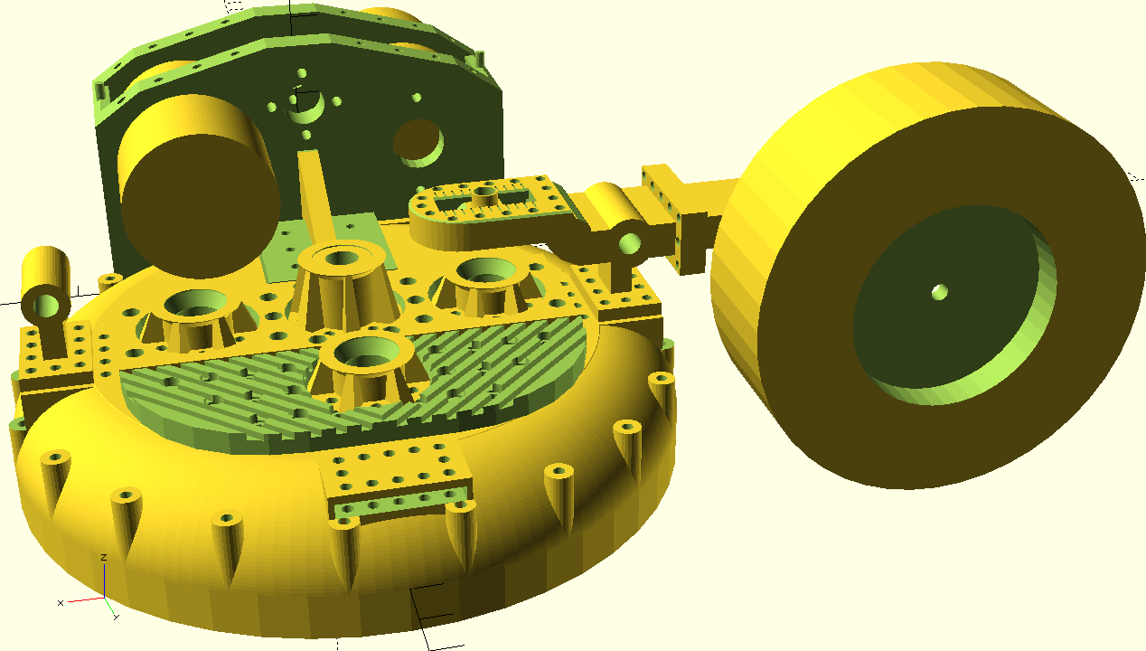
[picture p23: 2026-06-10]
Screenshots/Body_Assembly_Rev-A1_6-10-2026_1.png

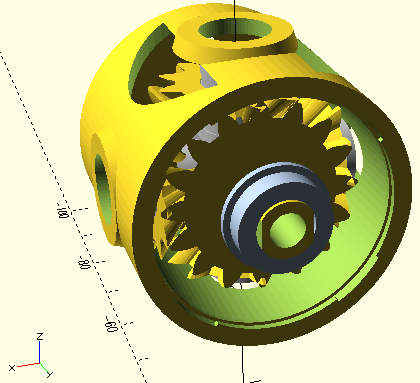
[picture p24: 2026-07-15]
Screenshots/Differential_Assembly_Rev-A1_7-15-2026_1.png

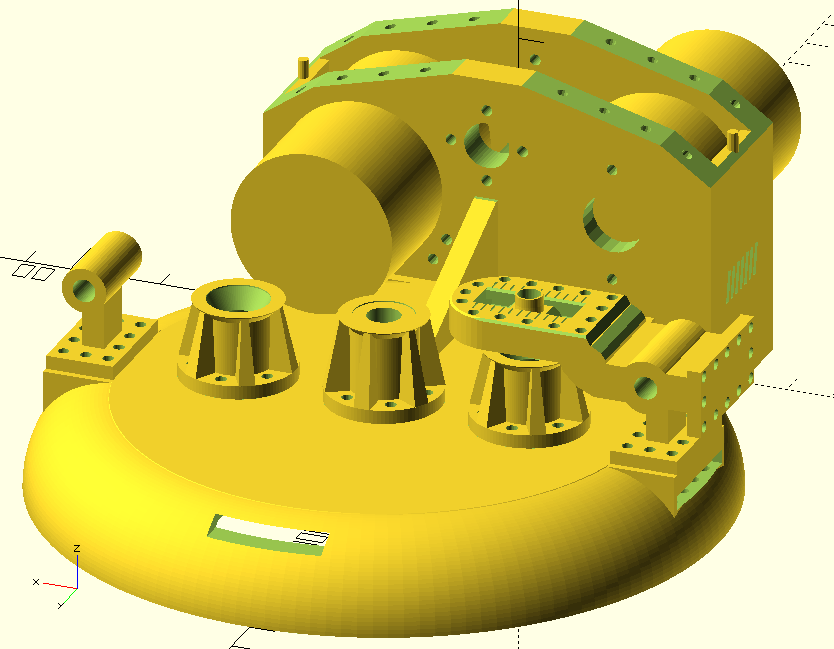
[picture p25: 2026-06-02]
Screenshots/Body_Assembly_Rev-A1_6-2-2026_1.png

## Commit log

2021-11-23 Getting ready to print the first pieces
    I plan on starting a test print soon of the center bracket.
    [Body.scad, Center_Bracket.scad, Center_Bracket_Sublime.scad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]
2026-05-24 Create Pulley_Layout_Sublime
2026-07-27 Revise damper design details in README
    Updated the specifications of the damper's roller bearing from 10mm to 18mm.
